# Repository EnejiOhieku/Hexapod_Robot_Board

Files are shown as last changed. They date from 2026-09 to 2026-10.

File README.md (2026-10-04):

# 18-DOF Hexapod Robot Controller Board (Rev 3.0)




[]()



A production-ready, high-power 4-layer robotics controller PCB designed for an **18-DOF Hexapod Robot**. Rev 3.0 is a major architectural upgrade introducing a **dedicated Vision Coprocessor** (second ESP32-S3-WROOM-1U-N8R8), a **BQ25886 2S LiPo fast charger** (replaces TP5100), **triple South-edge USB Type-C ports** (dedicated charging, main MCU, and vision MCU), an **OV3660/OV2640 DVP camera interface** with a 1–3W illumination LED driver, a **Sipeed MaixSense A010 3D ToF** sensor on a fully isolated 5V rail, a **dedicated Vision 3.3V ultra-low-noise LDO**, and an **external power switch connector**. The locomotion subsystem retains the proven dual 5A XL4015 buck split-rail architecture and dual PCA9685 uncrossed PWM routing.

---

## 3D Board Previews

<p align="center">
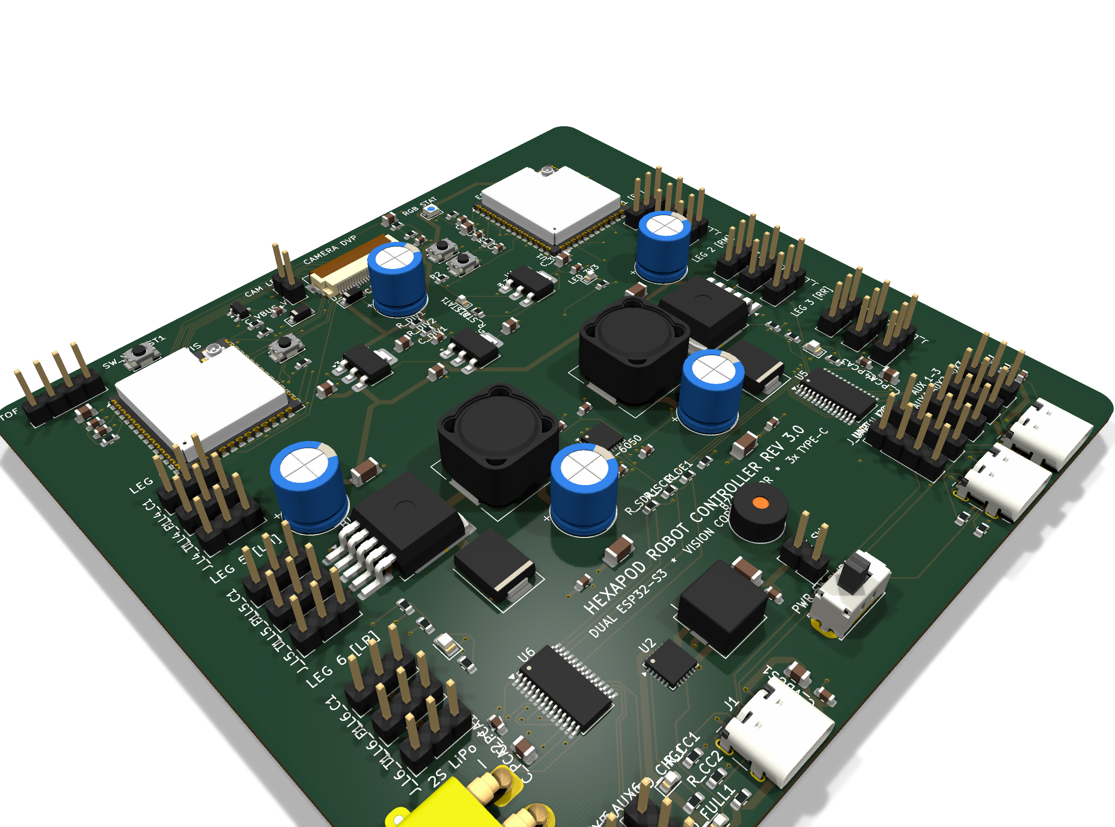
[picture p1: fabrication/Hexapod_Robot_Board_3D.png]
Hexapod Board 3D Perspective
  
</p>

<p align="center">
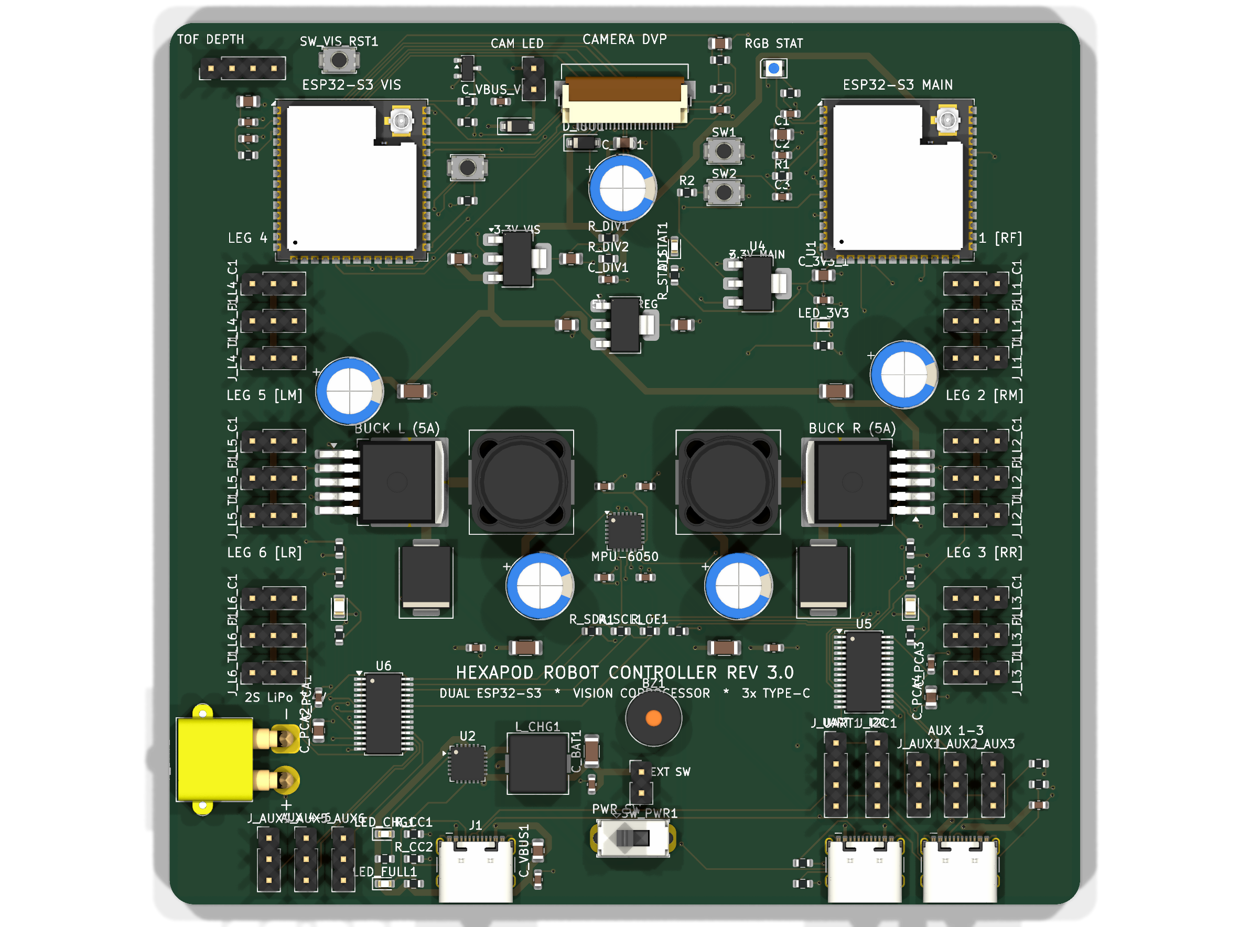
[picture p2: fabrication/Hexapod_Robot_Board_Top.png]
Top View
  
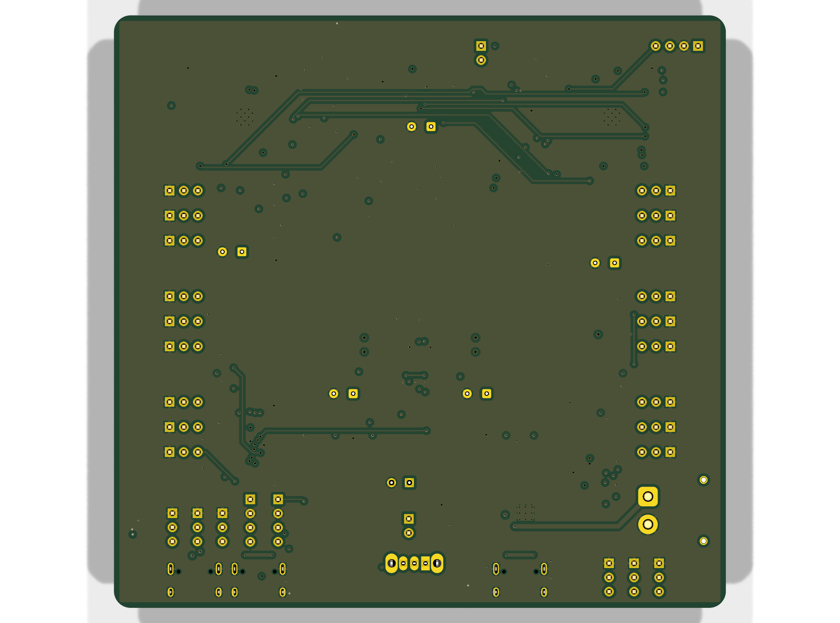
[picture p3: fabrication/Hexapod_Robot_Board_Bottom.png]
Bottom View
  
</p>

---

## System Architecture (Rev 3.0)

```mermaid
flowchart TD
    subgraph Power["Power & Battery Management"]
        J_CHG["USB Type-C (J_CHG) — Dedicated 2S Charger"] --> U2["BQ25886 2S LiPo Charger (8.4V / 1.5A)"]
        BAT["2S LiPo Battery (XT30PW, South Edge)"] --> SW["Main Power Switch (SW_PWR)"]
        U2 --> BAT
        SW --> VBAT_SW["Switched Battery Bus (VBAT_SW)"]
        VBAT_SW --> BUCK_L["Left Buck (XL4015, 5V / 5A) — U3_L"]
        VBAT_SW --> BUCK_R["Right Buck (XL4015, 5V / 5A) — U3_R"]
        VBAT_SW --> U4["Main 3.3V LDO (AP2112K / AMS1117-3.3) — U4"]
        VBAT_SW --> U_LDO_VIS["Vision 3.3V LDO (AMS1117-3.3) — U_LDO_VIS"]
        VBAT_SW --> U_REG_5V_TOF["Dedicated 5V ToF Regulator (AMS1117-5.0) — U_REG_5V_TOF"]
        VBAT_SW --> DIV["Battery Voltage Divider (R_DIV1 / R_DIV2)"]
    end

    subgraph Locomotion["Main Locomotion Controller (U1 — ESP32-S3-WROOM-1U)"]
        J_USB_MAIN["USB Type-C (J2) — Native USB / JTAG"] --> U1["ESP32-S3-WROOM-1U (Top-Right Edge, IPEX U.FL)"]
        U4 --> U1
        U1 -- "I2C (GPIO1/41)" --> U5["PCA9685 Left (0x40) — U5"]
        U1 -- "I2C (GPIO1/41)" --> U6["PCA9685 Right (0x41) — U6"]
        U1 -- "I2C (GPIO1/41)" --> U7["MPU-6050 6-Axis IMU (Centre, 0x68) — U7"]
        U7 -- "MPU_INT (GPIO10)" --> U1
        DIV -- "ADC (GPIO5)" --> U1
        U1 -- "GPIO48" --> LED_RGB_MAIN["WS2812B-2020 Status NeoPixel"]
    end

    subgraph Vision["Vision Coprocessor (U8 — ESP32-S3-WROOM-1U-N8R8)"]
        J_USB_VIS["USB Type-C (J3) — Vision USB / JTAG"] --> U8["ESP32-S3-WROOM-1U-N8R8 (Top-Left Edge, IPEX U.FL)"]
        U_LDO_VIS --> U8
        U8 -- "24-Pin 8-bit DVP (GPIO6-13, 15-18)" --> CAM["OV3660 / OV2640 Camera (J_CAM)"]
        U8 -- "SCCB I2C1 (GPIO4/5)" --> CAM
        U8 -- "UART1 (GPIO1/2)" --> TOF["Sipeed MaixSense A010 3D ToF (J_TOF)"]
        U8 -- "GPIO3 → R_CAM_LED → Q_CAM_LED" --> CAM_LED["1–3W Camera LED (J_CAM_LED)"]
        U_REG_5V_TOF -- "+5V_TOF (Isolated from Servos)" --> TOF
    end

    U1 <==>|"Inter-MCU Full-Duplex UART (GPIO43/44) + Frame Sync IRQ"| U8

    subgraph Servos["Servo Actuation (Split Left/Right Rails)"]
        BUCK_L --> V_SERVO_L["V_SERVO_L Plane (In2.Cu West)"]
        BUCK_R --> V_SERVO_R["V_SERVO_R Plane (In2.Cu East)"]
        U5 -- "PWM 0–11" --> SL["Left Legs 4, 5, 6 (9 Servos) + AUX 4–6"]
        U6 -- "PWM 0–11" --> SR["Right Legs 1, 2, 3 (9 Servos) + AUX 1–3"]
        V_SERVO_L --> SL
        V_SERVO_R --> SR
    end
```

---

## Key Hardware Features

### Dual-MCU Architecture
- **Main Locomotion MCU (`U1`)**: ESP32-S3-WROOM-1U — Dual-core Xtensa LX7 @ 240 MHz, 2.4 GHz Wi-Fi, BLE 5, 16 MB Flash. Placed on the **Top-Right edge** (`X=88.0, Y=2.5 mm`) with IPEX U.FL antenna facing North.
- **Vision Coprocessor (`U8`)**: ESP32-S3-WROOM-1U-N8R8 — Identical SoC, 8 MB PSRAM (Octal), pin-compatible with Zephyr's `esp32s3_eye` board definition. Placed on the **Top-Left edge** (`X=22.0, Y=2.5 mm`) with IPEX U.FL facing North.
- **Inter-MCU Link**: Full-duplex UART (`U1` GPIO43/44 ↔ `U8` GPIO43/44) at up to 3 Mbps, plus hardware Frame Sync / Alert IRQ (`U8` GPIO21 → `U1` GPIO4).

### Vision & Perception
- **Camera Interface**: 24-pin DVP FPC connector (`J_CAM`, top-centre `X=55.0, Y≈-11.0 mm`, rotated 180°) for OV3660 (3 MP) or OV2640 (2 MP). SCCB I²C via 4.7 kΩ pull-ups (`R_CAM_SCL`, `R_CAM_SDA`).
- **3D ToF Sensor**: Sipeed MaixSense A010 connector (`J_TOF`) at `(5.0, -11.0) mm`, powered by an isolated `+5V_TOF` linear rail with >60 dB PSRR to eliminate servo switching noise.
- **Camera Illumination**: 1–3 W white LED driver via AO3400A N-MOSFET (`Q_CAM_LED`), gate driven by Vision GPIO3 through 100 Ω series (`R_CAM_LED`) + 10 kΩ pull-down (`R_PD_CAM_LED`). External LED connector: `J_CAM_LED`.
- **Status NeoPixel**: WS2812B-2020 (`LED_RGB_MAIN`) driven by Main MCU GPIO48 via 330 Ω damping resistor (`R_NEO`).

### Power Architecture
| Rail | Source | Voltage | Max Current | Consumer |
|:---|:---|:---|:---|:---|
| `+VBAT` | 2S LiPo XT30PW | 6.0–8.4 V | 20 A peak | Raw battery |
| `VBAT_SW` | SW_PWR / J_SW_EXT | 6.0–8.4 V | 15 A | All regulators |
| `V_SERVO_L` | XL4015 Buck L (`U3_L`) | 5.0 V | 5 A cont. / 6 A pk | Left legs + AUX 4–6 |
| `V_SERVO_R` | XL4015 Buck R (`U3_R`) | 5.0 V | 5 A cont. / 6 A pk | Right legs + AUX 1–3 |
| `+3V3` | AP2112K LDO (`U4`) | 3.3 V | 600 mA | Main MCU, PCA9685s, IMU |
| `+3V3_VIS` | AMS1117-3.3 (`U_LDO_VIS`) | 3.3 V | 800 mA | Vision MCU, camera |
| `+5V_TOF` | AMS1117-5.0 (`U_REG_5V_TOF`) | 5.0 V | 800 mA | MaixSense A010 ToF (isolated) |
| `VBUS` | USB-C (`J_CHG`) | 5.0 V | 2.0 A | BQ25886 charger input |

- **Battery Management**: BQ25886 (VQFN-24) 2S LiPo fast charger — replaces TP5100. Supports USB BC1.2 detection, USB OTG boost, PowerPath management. Charge/standby LEDs: `LED_CHG`, `LED_FULL`.
- **External Power Switch**: 2-pin header `J_SW_EXT` allows robot chassis-mounted latching switch to gate `VBAT_SW`. Battery charges safely with electronics fully off.

### Triple South-Edge USB-C
All three USB-C receptacles co-located along the South board edge for a single chassis port bay cutout:
1. **`J_CHG` (`J1`, X≈37 mm)** — Dedicated 2S fast charger input. Zero data lines.
2. **`J_USB_MAIN` (`J2`, X≈95.5 mm)** — Main ESP32-S3 native USB / JTAG / gait telemetry.
3. **`J_USB_VISION` (`J3`, X≈84 mm)** — Vision ESP32-S3 native USB / JTAG / video stream.

### Inertial Measurement Unit
- **MPU-6050** (`U7`) at exact geometric centre of mass (`X=55.0, Y=45.0 mm`) with hardware interrupt to Main MCU GPIO10.

### Physical Specifications
- **Dimensions**: 110.0 × 90.0 mm, 3.0 mm corner radii.
- **Mounting**: 4× M3 holes (3.2 mm drill / 6.0 mm pad) at `(5,5)`, `(105,5)`, `(5,85)`, `(105,85)` mm.
- **Stackup**: 4-layer — `F.Cu` signals/PDN · `In1.Cu` solid GND · `In2.Cu` split `V_SERVO` planes · `B.Cu` GND flood/signals.

---

## Servo Channel Mapping

| Joint / Channel | Header | Controller | Ch | I²C Addr | Rail |
|:---|:---|:---|:---|:---|:---|
| **Right Front (RF) Coxa** | `J_L1_C` | PCA9685 Right (`U6`) | PWM 0 | `0x41` | `V_SERVO_R` |
| **Right Front (RF) Femur** | `J_L1_F` | PCA9685 Right (`U6`) | PWM 1 | `0x41` | `V_SERVO_R` |
| **Right Front (RF) Tibia** | `J_L1_T` | PCA9685 Right (`U6`) | PWM 2 | `0x41` | `V_SERVO_R` |
| **Right Middle (RM) Coxa** | `J_L2_C` | PCA9685 Right (`U6`) | PWM 3 | `0x41` | `V_SERVO_R` |
| **Right Middle (RM) Femur** | `J_L2_F` | PCA9685 Right (`U6`) | PWM 4 | `0x41` | `V_SERVO_R` |
| **Right Middle (RM) Tibia** | `J_L2_T` | PCA9685 Right (`U6`) | PWM 5 | `0x41` | `V_SERVO_R` |
| **Right Rear (RR) Coxa** | `J_L3_C` | PCA9685 Right (`U6`) | PWM 6 | `0x41` | `V_SERVO_R` |
| **Right Rear (RR) Femur** | `J_L3_F` | PCA9685 Right (`U6`) | PWM 7 | `0x41` | `V_SERVO_R` |
| **Right Rear (RR) Tibia** | `J_L3_T` | PCA9685 Right (`U6`) | PWM 8 | `0x41` | `V_SERVO_R` |
| **Left Front (LF) Coxa** | `J_L4_C` | PCA9685 Left (`U5`) | PWM 0 | `0x40` | `V_SERVO_L` |
| **Left Front (LF) Femur** | `J_L4_F` | PCA9685 Left (`U5`) | PWM 1 | `0x40` | `V_SERVO_L` |
| **Left Front (LF) Tibia** | `J_L4_T` | PCA9685 Left (`U5`) | PWM 2 | `0x40` | `V_SERVO_L` |
| **Left Middle (LM) Coxa** | `J_L5_C` | PCA9685 Left (`U5`) | PWM 3 | `0x40` | `V_SERVO_L` |
| **Left Middle (LM) Femur** | `J_L5_F` | PCA9685 Left (`U5`) | PWM 4 | `0x40` | `V_SERVO_L` |
| **Left Middle (LM) Tibia** | `J_L5_T` | PCA9685 Left (`U5`) | PWM 5 | `0x40` | `V_SERVO_L` |
| **Left Rear (LR) Coxa** | `J_L6_C` | PCA9685 Left (`U5`) | PWM 6 | `0x40` | `V_SERVO_L` |
| **Left Rear (LR) Femur** | `J_L6_F` | PCA9685 Left (`U5`) | PWM 7 | `0x40` | `V_SERVO_L` |
| **Left Rear (LR) Tibia** | `J_L6_T` | PCA9685 Left (`U5`) | PWM 8 | `0x40` | `V_SERVO_L` |
| **Auxiliary PWM 1–3** | `J_AUX1–3` | PCA9685 Right (`U6`) | PWM 9–11 | `0x41` | `V_SERVO_R` |
| **Auxiliary PWM 4–6** | `J_AUX4–6` | PCA9685 Left (`U5`) | PWM 9–11 | `0x40` | `V_SERVO_L` |

---

## GPIO Assignments

### Main Locomotion MCU (`U1` — ESP32-S3-WROOM-1U)
| GPIO | Function | Direction | Connected To |
|:---|:---|:---|:---|
| GPIO1 | I2C SCL | Output | PCA9685 L/R, MPU-6050 |
| GPIO41 | I2C SDA | Bidirectional | PCA9685 L/R, MPU-6050 |
| GPIO4 | Frame Sync IRQ | Input | Vision MCU GPIO21 |
| GPIO5 | Battery ADC | Input | `R_DIV1`/`R_DIV2` voltage divider |
| GPIO6 | CHG_STAT | Input | BQ25886 `STAT` pin |
| GPIO7 | CHG_PG | Input | BQ25886 `PG` pin (Power Good) |
| GPIO10 | MPU_INT | Input | MPU-6050 INT |
| GPIO19/20 | USB D-/D+ | Bidirectional | `J_USB_MAIN` (J2) |
| GPIO43 | Inter-MCU TX | Output | Vision MCU GPIO44 |
| GPIO44 | Inter-MCU RX | Input | Vision MCU GPIO43 |
| GPIO48 | NeoPixel Data | Output | `R_NEO` → `LED_RGB_MAIN` |

### Vision Coprocessor (`U8` — ESP32-S3-WROOM-1U-N8R8)
| GPIO | Function | Direction | Connected To |
|:---|:---|:---|:---|
| GPIO1 | ToF UART RX | Input | A010 TX (UART1) |
| GPIO2 | ToF UART TX | Output | A010 RX (UART1) |
| GPIO3 | Camera LED PWM | Output | `R_CAM_LED` → `Q_CAM_LED` gate |
| GPIO4 | SCCB SDA (I2C1) | Bidirectional | Camera SIOD, 4.7 kΩ pull-up |
| GPIO5 | SCCB SCL (I2C1) | Output | Camera SIOC, 4.7 kΩ pull-up |
| GPIO6 | DVP VSYNC | Input | Camera VSYNC |
| GPIO7 | DVP HREF | Input | Camera HREF |
| GPIO8–13 | DVP D2–D7 | Input | Camera Y4–Y9 |
| GPIO15 | DVP XCLK | Output | Camera XCLK (10–24 MHz) |
| GPIO16–18 | DVP D0–D2 | Input | Camera Y2–Y4 |
| GPIO19/20 | USB D-/D+ | Bidirectional | `J_USB_VISION` (J3) |
| GPIO21 | Frame Sync IRQ | Output | Main MCU GPIO4 |
| GPIO38 | Camera PWDN | Output | Camera PWDN, 10 kΩ pull-down |
| GPIO43 | Inter-MCU TX | Output | Main MCU GPIO44 |
| GPIO44 | Inter-MCU RX | Input | Main MCU GPIO43 |

---

## Project Structure

```
Hexapod_Robot_Board/
├── Hexapod_Robot_Board.kicad_pro       # Master KiCad 10.0.6 project file
├── Hexapod_Robot_Board.kicad_sch       # Rev 3.0 schematic (dual-MCU, triple USB-C)
├── Hexapod_Robot_Board.kicad_pcb       # 4-layer routed PCB layout
├── Hexapod_Robot_Board.net             # Complete netlist (98 nets)
├── README.md                           # This document
├── 3dmodels/                           # Custom 3D STEP component packages
│   ├── ESP32-S3-WROOM-1U.step
│   ├── MPU-6050.step
│   ├── LED_WS2812B-2020.step
│   └── Hirose_FH12-24S-0.5SH_1x24-1MP_P0.50mm_Horizontal.step
├── fabrication/                        # Manufacturing deliverable package
│   ├── Hexapod_Robot_Board-gerbers.zip
│   ├── Hexapod_Robot_Board-cpl-jlcpcb.csv
│   ├── Hexapod_Robot_Board-bom-jlcpcb.csv
│   ├── Hexapod_Robot_Board.step
│   ├── Hexapod_Robot_Board_Schematic.pdf
│   └── *.png                           # 2D + 3D renders
├── reports/                            # Verification reports
│   ├── Hexapod_Robot_Board-drc.rpt
│   ├── Hexapod_Robot_Board-erc.rpt
│   └── Hexapod_Robot_Board-stats.txt
└── scripts/                            # Python automation suite
    ├── export_fabrication.py           # One-click manufacturing pipeline
    ├── run_final_perfect_route.py      # Freerouting solver
    └── README.md
```

---

## Verification & Compliance

- **ERC**: Passed — **0 errors, 0 warnings** ([`reports/Hexapod_Robot_Board-erc.rpt`](reports/Hexapod_Robot_Board-erc.rpt)).
- **DRC**: Passed — **0 violations, 0 unconnected items** ([`reports/Hexapod_Robot_Board-drc.rpt`](reports/Hexapod_Robot_Board-drc.rpt)).
- **Manufacturability**: JLCPCB / PCBWay 4-layer standard constraints (0.15 mm clearance, 0.20 mm min track, 0.30 mm min drill, 45° mitered geometry).

---

## Revision History

| Rev | Date | Summary |
|:---|:---|:---|
| **3.0** | 2026-10-04 | Vision Coprocessor (ESP32-S3-WROOM-1U-N8R8), BQ25886 2S charger, triple South USB-C, DVP camera, MaixSense A010 ToF on isolated +5V rail, dedicated Vision 3.3V LDO, camera LED driver, inter-MCU UART link, external power switch header, WS2812B NeoPixel. Schematic/PCB annotated and synced. |
| **2.0** | 2026-10-01 | ESP32-S3-WROOM-1U, dual XL4015 5A buck split rails, MPU-6050 at CoM, South-edge USB-C charging via TP5100, dual PCA9685 uncrossed PWM, 4-layer routing, 0 DRC/ERC. |
| **1.0** | 2026-09-28 | Initial 18-DOF hexapod controller. ESP32-S3, single buck, TP5100 charger, dual PCA9685. |

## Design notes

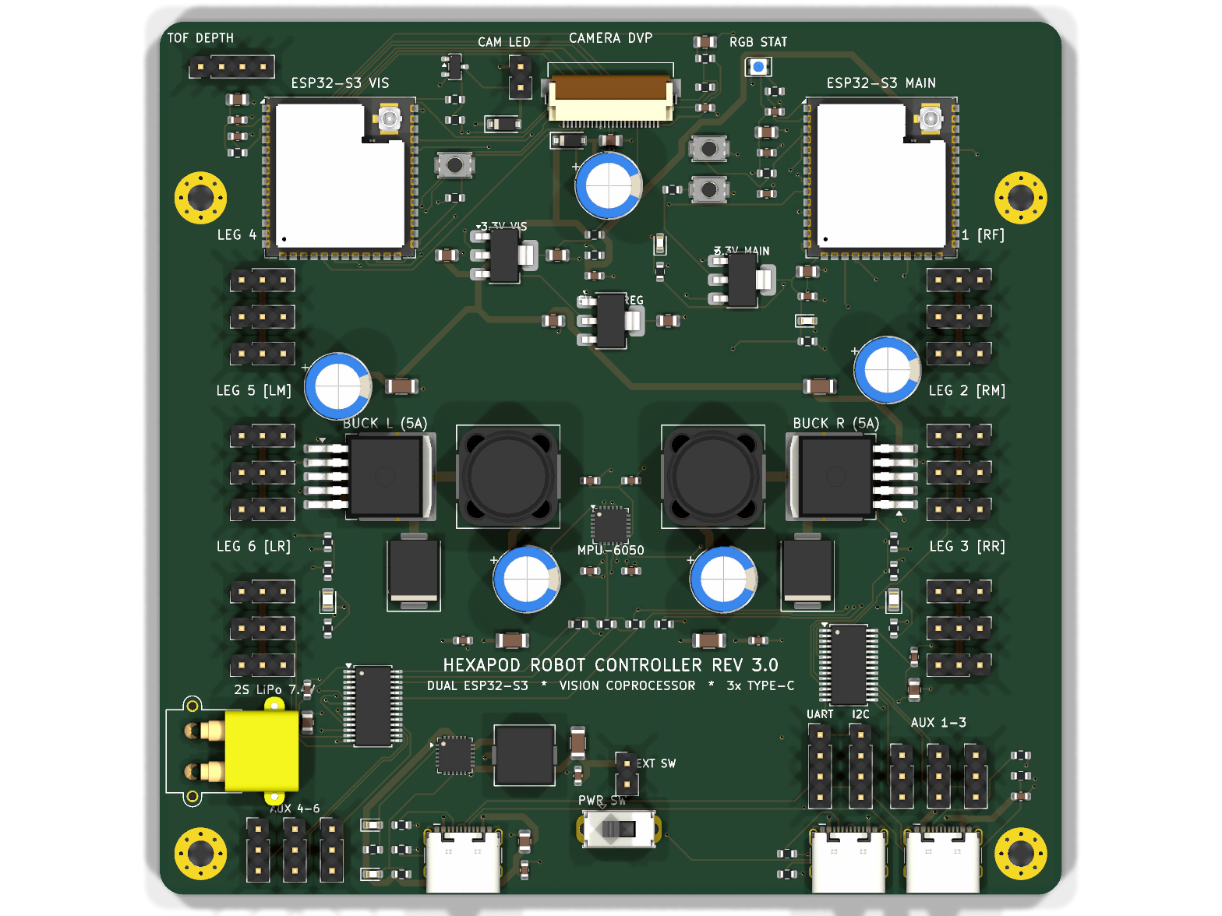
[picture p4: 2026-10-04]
reports/current_board.png

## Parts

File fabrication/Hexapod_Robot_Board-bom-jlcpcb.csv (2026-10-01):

Item | Designator | Quantity | Value | Package/Footprint | Type | LCSC Part #
1 | C2, C_3V3_2, C_BAT2, C_DIV, C_MPU1, C_MPU2, C_MPU3, C_OUT3_L, C_OUT3_R, C_PCA1, C_PCA3, C_VBUS2 | 12 | 100nF | C_0603_1608Metric | SMD | C14663
2 | C3 | 1 | 1uF | C_0603_1608Metric | SMD | C15849
3 | C_MPU5 | 1 | 2.2nF | C_0603_1608Metric | SMD | C1604
4 | C1, C_ISO2, C_PCA2, C_PCA4, C_VBUS1 | 5 | 10uF | C_0805_2012Metric | SMD | C15850
5 | C_3V3_1 | 1 | 22uF | C_0805_2012Metric | SMD | C45783
6 | C_BAT1 | 1 | 22uF | C_1206_3216Metric | SMD | C45783
7 | C_OUT2_L, C_OUT2_R | 2 | 22uF_16V | C_1206_3216Metric | SMD
8 | C_IN2_L, C_IN2_R | 2 | 22uF_25V | C_1206_3216Metric | SMD
9 | D_CATCH_L, D_CATCH_R | 2 | SS54 | D_SMC | SMD | C22452
10 | D_ISO | 1 | SS14 | D_SOD-123 | SMD | C2410
11 | U1 | 1 | ESP32-S3-WROOM-1U | ESP32-S3-WROOM-1U | SMD | C2934560
12 | U7 | 1 | MPU-6050 | InvenSense_QFN-24_4x4mm_P0.5mm | SMD | C24112
13 | LED_3V3 | 1 | Blue | LED_0603_1608Metric | SMD
14 | D_STAT, LED_FULL | 2 | Green | LED_0603_1608Metric | SMD
15 | LED_CHG | 1 | Red | LED_0603_1608Metric | SMD
16 | LED_L, LED_R | 2 | Green | LED_0805_2012Metric | SMD
17 | L_SERVO_L, L_SERVO_R | 2 | 10uH_10A | L_12x12mm_H8mm | SMD
18 | L_CHG | 1 | 2.2uH_4A | L_7.3x7.3_H4.5 | SMD
19 | U2 | 1 | BQ25886 | QFN-24-1EP_4x4mm_P0.5mm_EP2.7x2.7mm_ThermalVias | SMD
20 | R_DIV1 | 1 | 100k_1% | R_0603_1608Metric | SMD
21 | R1, R2, R_OE | 3 | 10k | R_0603_1608Metric | SMD | C25804
22 | R_FB1_L, R_FB1_R | 2 | 10k_1% | R_0603_1608Metric | SMD
23 | R_3V3_LED, R_BZ, R_CHG, R_FULL, R_LED_L, R_LED_R, R_STAT | 7 | 1k | R_0603_1608Metric | SMD | C21190
24 | R_FB2_L, R_FB2_R | 2 | 3.16k_1% | R_0603_1608Metric | SMD
25 | R_DIV2 | 1 | 33k_1% | R_0603_1608Metric | SMD
26 | R_SCL, R_SDA | 2 | 4.7k | R_0603_1608Metric | SMD
27 | R_CC1, R_CC2 | 2 | 5.1k | R_0603_1608Metric | SMD | C23186
28 | U4 | 1 | AMS1117-3.3 | SOT-223-3_TabPin2 | SMD | C6186
29 | SW2 | 1 | BOOT | SW_Push_SPST_NO_Alps_SKRK | SMD
30 | SW1 | 1 | RESET | SW_Push_SPST_NO_Alps_SKRK | SMD
31 | U3_L, U3_R | 2 | XL4015 | TO-263-5_TabPin3 | SMD | C73335
32 | U5 | 1 | PCA9685_1 | TSSOP-28_4.4x9.7mm_P0.65mm | SMD
33 | U6 | 1 | PCA9685_2 | TSSOP-28_4.4x9.7mm_P0.65mm | SMD
34 | J1 | 1 | USB-C | USB_C_Receptacle_HCTL_HC-TYPE-C-16P-01A | SMD
35 | J_BAT | 1 | 2S_LiPo | AMASS_XT30PW-M_1x02_P2.50mm_Horizontal | THT
36 | C_OUT1_L, C_OUT1_R | 2 | 1000uF_10V | CP_Radial_D8.0mm_P3.50mm | THT
37 | C_IN1_L, C_IN1_R | 2 | 100uF_25V | CP_Radial_D8.0mm_P3.50mm | THT
38 | C_ISO1 | 1 | 220uF_16V | CP_Radial_D8.0mm_P3.50mm | THT
39 | H1, H2, H3, H4 | 4 | M3 | MountingHole_3.2mm_M3_Pad_Via | THT
40 | J_AUX1 | 1 | AUX_1 | PinHeader_1x03_P2.54mm_Vertical | THT
41 | J_AUX2 | 1 | AUX_2 | PinHeader_1x03_P2.54mm_Vertical | THT
42 | J_AUX3 | 1 | AUX_3 | PinHeader_1x03_P2.54mm_Vertical | THT
43 | J_AUX4 | 1 | AUX_4 | PinHeader_1x03_P2.54mm_Vertical | THT
44 | J_AUX5 | 1 | AUX_5 | PinHeader_1x03_P2.54mm_Vertical | THT
45 | J_AUX6 | 1 | AUX_6 | PinHeader_1x03_P2.54mm_Vertical | THT
46 | J_L4_C | 1 | LF_Coxa | PinHeader_1x03_P2.54mm_Vertical | THT
47 | J_L4_F | 1 | LF_Femur | PinHeader_1x03_P2.54mm_Vertical | THT
48 | J_L4_T | 1 | LF_Tibia | PinHeader_1x03_P2.54mm_Vertical | THT
49 | J_L5_C | 1 | LM_Coxa | PinHeader_1x03_P2.54mm_Vertical | THT
50 | J_L5_F | 1 | LM_Femur | PinHeader_1x03_P2.54mm_Vertical | THT
51 | J_L5_T | 1 | LM_Tibia | PinHeader_1x03_P2.54mm_Vertical | THT
52 | J_L6_C | 1 | LR_Coxa | PinHeader_1x03_P2.54mm_Vertical | THT
53 | J_L6_F | 1 | LR_Femur | PinHeader_1x03_P2.54mm_Vertical | THT
54 | J_L6_T | 1 | LR_Tibia | PinHeader_1x03_P2.54mm_Vertical | THT
55 | J_L1_C | 1 | RF_Coxa | PinHeader_1x03_P2.54mm_Vertical | THT
56 | J_L1_F | 1 | RF_Femur | PinHeader_1x03_P2.54mm_Vertical | THT
57 | J_L1_T | 1 | RF_Tibia | PinHeader_1x03_P2.54mm_Vertical | THT
58 | J_L2_C | 1 | RM_Coxa | PinHeader_1x03_P2.54mm_Vertical | THT
59 | J_L2_F | 1 | RM_Femur | PinHeader_1x03_P2.54mm_Vertical | THT
60 | J_L2_T | 1 | RM_Tibia | PinHeader_1x03_P2.54mm_Vertical | THT
61 | J_L3_C | 1 | RR_Coxa | PinHeader_1x03_P2.54mm_Vertical | THT
62 | J_L3_F | 1 | RR_Femur | PinHeader_1x03_P2.54mm_Vertical | THT
63 | J_L3_T | 1 | RR_Tibia | PinHeader_1x03_P2.54mm_Vertical | THT
64 | J_I2C | 1 | I2C_BUS | PinHeader_1x04_P2.54mm_Vertical | THT
65 | J_UART | 1 | UART_DEBUG | PinHeader_1x04_P2.54mm_Vertical | THT
66 | SW_PWR | 1 | POWER | SW_Slide_SPDT_Straight_CK_OS102011MS2Q | THT

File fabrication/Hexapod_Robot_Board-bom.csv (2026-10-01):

Designator | Value | Footprint | Quantity
C1,C_ISO2,C_PCA2,C_PCA4,C_VBUS1 | 10uF | Capacitor_SMD:C_0805_2012Metric | 5
C2,C_3V3_2,C_BAT2,C_DIV?,C_MPU1-C_MPU3,C_OUT3_L?,C_OUT3_R?,C_PCA1,C_PCA3,C_VBUS2 | 100nF | Capacitor_SMD:C_0603_1608Metric | 12
C3 | 1uF | Capacitor_SMD:C_0603_1608Metric | 1
C_3V3_1 | 22uF | Capacitor_SMD:C_0805_2012Metric | 1
C_BAT1,C_IN2_L?,C_IN2_R? | 22uF_25V | Capacitor_SMD:C_1206_3216Metric | 3
C_IN1_L?,C_IN1_R? | 100uF_25V | Capacitor_THT:CP_Radial_D8.0mm_P3.50mm | 2
C_ISO1 | 220uF_16V | Capacitor_THT:CP_Radial_D8.0mm_P3.50mm | 1
C_MPU5 | 2.2nF | Capacitor_SMD:C_0603_1608Metric | 1
C_OUT1_L?,C_OUT1_R? | 1000uF_10V | Capacitor_THT:CP_Radial_D8.0mm_P3.50mm | 2
C_OUT2_L?,C_OUT2_R? | 22uF_16V | Capacitor_SMD:C_1206_3216Metric | 2
D_CATCH_L?,D_CATCH_R? | SS54 | Diode_SMD:D_SMC | 2
D_ISO? | SS14 | Diode_SMD:D_SOD-123 | 1
D_STAT?,LED_FULL? | Green | LED_SMD:LED_0603_1608Metric | 2
J1 | USB-C | Connector_USB:USB_C_Receptacle_HCTL_HC-TYPE-C-16P-01A | 1
J_AUX1 | AUX_PWM_18 | Connector_PinHeader_2.54mm:PinHeader_1x03_P2.54mm_Vertical | 1
J_AUX2 | AUX_PWM_19 | Connector_PinHeader_2.54mm:PinHeader_1x03_P2.54mm_Vertical | 1
J_AUX3 | AUX_PWM_20 | Connector_PinHeader_2.54mm:PinHeader_1x03_P2.54mm_Vertical | 1
J_AUX4 | AUX_PWM_21 | Connector_PinHeader_2.54mm:PinHeader_1x03_P2.54mm_Vertical | 1
J_AUX5 | AUX_PWM_22 | Connector_PinHeader_2.54mm:PinHeader_1x03_P2.54mm_Vertical | 1
J_AUX6 | AUX_PWM_23 | Connector_PinHeader_2.54mm:PinHeader_1x03_P2.54mm_Vertical | 1
J_BAT? | 2S_LiPo_7.4V | Connector_AMASS:AMASS_XT30PW-M_1x02_P2.50mm_Horizontal | 1
J_I2C? | I2C_BUS | Connector_PinHeader_2.54mm:PinHeader_1x04_P2.54mm_Vertical | 1
J_L1_C? | L1_Coxa | Connector_PinHeader_2.54mm:PinHeader_1x03_P2.54mm_Vertical | 1
J_L1_F? | L1_Femur | Connector_PinHeader_2.54mm:PinHeader_1x03_P2.54mm_Vertical | 1
J_L1_T? | L1_Tibia | Connector_PinHeader_2.54mm:PinHeader_1x03_P2.54mm_Vertical | 1
J_L2_C? | L2_Coxa | Connector_PinHeader_2.54mm:PinHeader_1x03_P2.54mm_Vertical | 1
J_L2_F? | L2_Femur | Connector_PinHeader_2.54mm:PinHeader_1x03_P2.54mm_Vertical | 1
J_L2_T? | L2_Tibia | Connector_PinHeader_2.54mm:PinHeader_1x03_P2.54mm_Vertical | 1
J_L3_C? | L3_Coxa | Connector_PinHeader_2.54mm:PinHeader_1x03_P2.54mm_Vertical | 1
J_L3_F? | L3_Femur | Connector_PinHeader_2.54mm:PinHeader_1x03_P2.54mm_Vertical | 1
J_L3_T? | L3_Tibia | Connector_PinHeader_2.54mm:PinHeader_1x03_P2.54mm_Vertical | 1
J_L4_C? | L4_Coxa | Connector_PinHeader_2.54mm:PinHeader_1x03_P2.54mm_Vertical | 1
J_L4_F? | L4_Femur | Connector_PinHeader_2.54mm:PinHeader_1x03_P2.54mm_Vertical | 1
J_L4_T? | L4_Tibia | Connector_PinHeader_2.54mm:PinHeader_1x03_P2.54mm_Vertical | 1
J_L5_C? | L5_Coxa | Connector_PinHeader_2.54mm:PinHeader_1x03_P2.54mm_Vertical | 1
J_L5_F? | L5_Femur | Connector_PinHeader_2.54mm:PinHeader_1x03_P2.54mm_Vertical | 1
J_L5_T? | L5_Tibia | Connector_PinHeader_2.54mm:PinHeader_1x03_P2.54mm_Vertical | 1
J_L6_C? | L6_Coxa | Connector_PinHeader_2.54mm:PinHeader_1x03_P2.54mm_Vertical | 1
J_L6_F? | L6_Femur | Connector_PinHeader_2.54mm:PinHeader_1x03_P2.54mm_Vertical | 1
J_L6_T? | L6_Tibia | Connector_PinHeader_2.54mm:PinHeader_1x03_P2.54mm_Vertical | 1
J_UART? | UART_DEBUG | Connector_PinHeader_2.54mm:PinHeader_1x04_P2.54mm_Vertical | 1
LED_3V3 | Blue | LED_SMD:LED_0603_1608Metric | 1
LED_CHG? | Red | LED_SMD:LED_0603_1608Metric | 1
LED_L?,LED_R? | Green | LED_SMD:LED_0805_2012Metric | 2
L_CHG? | 2.2uH_4A | Inductor_SMD:L_7.3x7.3_H4.5 | 1
L_SERVO_L?,L_SERVO_R? | 10uH_10A | Inductor_SMD:L_12x12mm_H8mm | 2
R1,R2,R_OE? | 10k | Resistor_SMD:R_0603_1608Metric | 3
R_3V3_LED?,R_BZ?,R_CHG?,R_FULL?,R_LED_L?,R_LED_R?,R_STAT? | 1k | Resistor_SMD:R_0603_1608Metric | 7
R_CC1,R_CC2 | 5.1k_1% | Resistor_SMD:R_0603_1608Metric | 2
R_DIV1 | 100k_1% | Resistor_SMD:R_0603_1608Metric | 1
R_DIV2 | 33k_1% | Resistor_SMD:R_0603_1608Metric | 1
R_FB1_L?,R_FB1_R? | 10k_1% | Resistor_SMD:R_0603_1608Metric | 2
R_FB2_L?,R_FB2_R? | 3.16k_1% | Resistor_SMD:R_0603_1608Metric | 2
R_SCL?,R_SDA? | 4.7k | Resistor_SMD:R_0603_1608Metric | 2
SW1 | RESET | Button_Switch_SMD:SW_Push_SPST_NO_Alps_SKRK | 1
SW2 | BOOT | Button_Switch_SMD:SW_Push_SPST_NO_Alps_SKRK | 1
SW_PWR? | POWER_SWITCH | Button_Switch_THT:SW_Slide_SPDT_Straight_CK_OS102011MS2Q | 1
U1 | ESP32-S3-WROOM-1U | RF_Module:ESP32-S3-WROOM-1U | 1
U2 | BQ25886 | Package_DFN_QFN:QFN-24-1EP_4x4mm_P0.5mm_EP2.7x2.7mm_ThermalVias | 1
U3_L?,U3_R? | XL4015 | Package_TO_SOT_SMD:TO-263-5_TabPin3 | 2
U4 | AMS1117-3.3 | Package_TO_SOT_SMD:SOT-223-3_TabPin2 | 1
U5 | PCA9685_0x40 | Package_SO:TSSOP-28_4.4x9.7mm_P0.65mm | 1
U6 | PCA9685_0x41 | Package_SO:TSSOP-28_4.4x9.7mm_P0.65mm | 1
U7 | MPU-6050 | Sensor_Motion:InvenSense_QFN-24_4x4mm_P0.5mm | 1

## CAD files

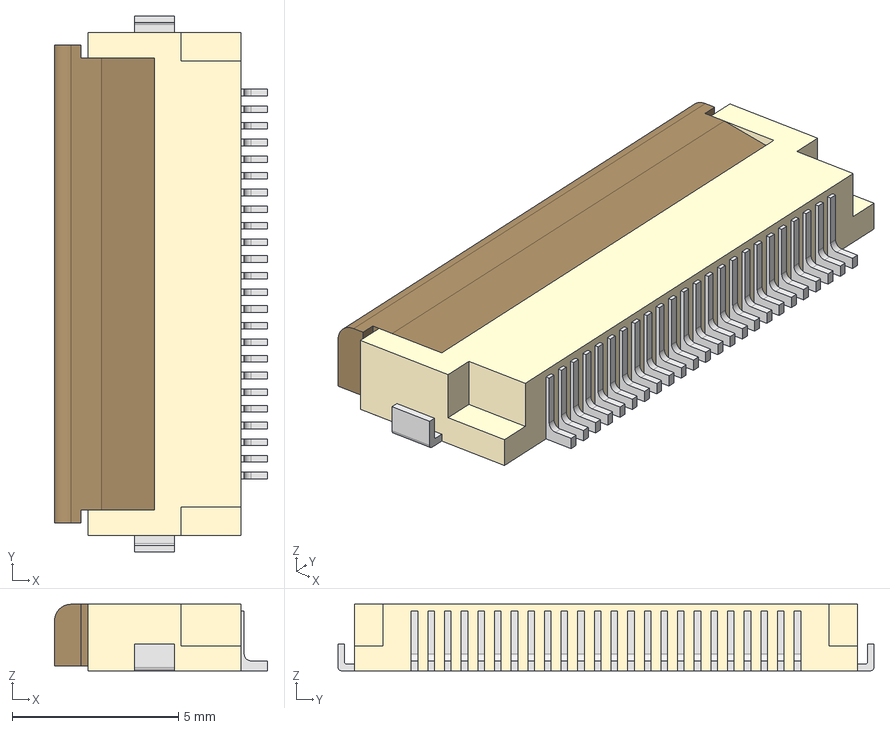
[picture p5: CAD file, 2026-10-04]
3dmodels/Hirose_FH12-24S-0.5SH_1x24-1MP_P0.50mm_Horizontal.step
6.40 x 16.1 x 2.00 mm

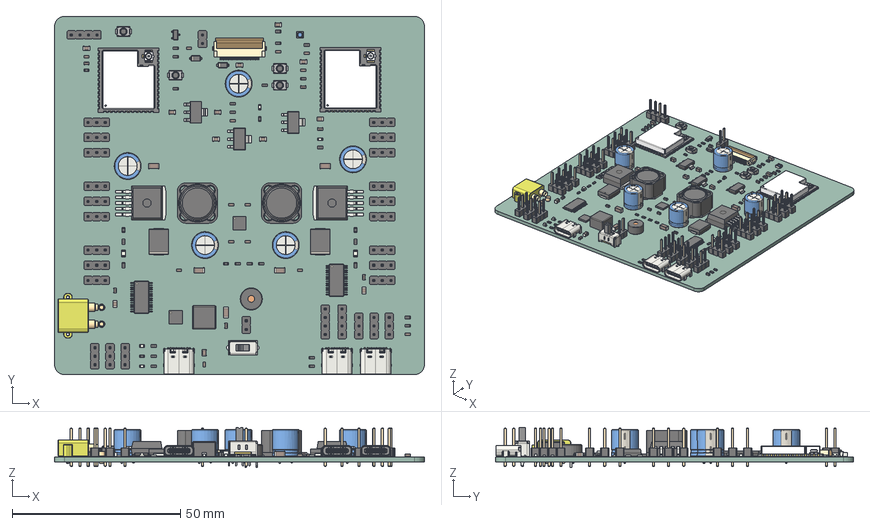
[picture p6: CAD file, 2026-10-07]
fabrication/Hexapod_Robot_Board.step
110.0 x 106.5 x 12.0 mm
PinHeader_1x03_P254mm_Vertical x 24
R_0603_1608Metric x 31
C_0603_1608Metric x 20
D_SMC x 2
C_1206_3216Metric x 5
CQ assembly x 2
a648ce36-9c39-11ed-93f0-dde97e994e83 x 2
a648ce37-9c39-11ed-93f0-dde97e994e83 x 2
a648ce37-9c39-11ed-93f0-dde97e994e83_part x 2
a648ce38-9c39-11ed-93f0-dde97e994e83 x 2
a648ce38-9c39-11ed-93f0-dde97e994e83_part x 2
a648ce39-9c39-11ed-93f0-dde97e994e83 x 2
a648ce39-9c39-11ed-93f0-dde97e994e83_part x 2
L_Coilcraft_MSS1278-XXX x 2
C_0805_2012Metric x 12
XT30PW-M
SW_Push_SPST_NO_Alps_SKRK x 4
LED_0805_2012Metric x 2
PinHeader_1x04_P254mm_Vertical x 3
SOT-223 x 3
D_SOD-123 x 2
TSSOP-28_4.4x9.7mm_P0.65mm x 2
CP_Radial_D80mm_P350mm x 5
PinHeader_1x02_P254mm_Vertical x 2
LED_0603_1608Metric x 4
R0201_20210301.STEP^R0201_20210301.STEP_Submodel-R0201_part_ DesignRootModel_ESP32-S3-WROOM-1U(2)_ESP32-S3-WROOM-1U_2 x 16
L0201_20210301.STEP^L0201_20210301.STEP_Submodel-L0201_part_ DesignRootModel_ESP32-S3-WROOM-1U(2)_ESP32-S3-WROOM-1U_2 x 4
C0201_20210301.STEP^C0201_20210301.STEP_Submodel-C0201_part_ DesignRootModel_ESP32-S3-WROOM-1U(2)_ESP32-S3-WROOM-1U_2 x 26
C0402_20210301.STEP^C0402_20210301.STEP_Submodel-C0402_part_ DesignRootModel_ESP32-S3-WROOM-1U(2)_ESP32-S3-WROOM-1U_2 x 2
I-IPEX.STEP^I-IPEX.STEP_Submodel-IPEX_3P_part_DesignRootModel_ ESP32-S3-WROOM-1U(2)_ESP32-S3-WROOM-1U_2 x 2
DFN1006.STEP^DFN1006.STEP_Submodel-SOD882_part_DesignRootModel_ ESP32-S3-WROOM-1U(2)_ESP32-S3-WROOM-1U_2 x 2
SOP8_rev1_20210308.STEP^SOP8_rev1_20210308.STEP_Submodel-SOP8_1P27_6P6_ part_DesignRootModel_ESP32-S3-WROOM-1U(2)_ESP32-S3-WROOM-1U_2 x 2
ESP32-S3_20210301.STEP^ESP32-S3_20210301.STEP_Submodel-QFN56_0P4_7_ part_DesignRootModel_ESP32-S3-WROOM-1U(2)_ESP32-S3-WROOM-1U_2 x 2
XTAL3225_20210301.STEP^XTAL3225_20210301.STEP_Submodel-XTAL3225_part_ DesignRootModel_ESP32-S3-WROOM-1U(2)_ESP32-S3-WROOM-1U_2 x 2
uid__4-111^DesignRootModel_ESP32-S3-WROOM-1U(2)_ESP32-S3-WROOM-1U_2 x 2
uid__4-112^DesignRootModel_ESP32-S3-WROOM-1U(2)_ESP32-S3-WROOM-1U_2 x 2
uid__4-113^DesignRootModel_ESP32-S3-WROOM-1U(2)_ESP32-S3-WROOM-1U_2 x 2
uid__4-130^DesignRootModel_ESP32-S3-WROOM-1U(2)_ESP32-S3-WROOM-1U_2 x 2
uid__4-131^DesignRootModel_ESP32-S3-WROOM-1U(2)_ESP32-S3-WROOM-1U_2 x 2
uid__4-132^DesignRootModel_ESP32-S3-WROOM-1U(2)_ESP32-S3-WROOM-1U_2 x 2
uid__4-148^DesignRootModel_ESP32-S3-WROOM-1U(2)_ESP32-S3-WROOM-1U_2 x 2
uid__4-149^DesignRootModel_ESP32-S3-WROOM-1U(2)_ESP32-S3-WROOM-1U_2 x 2
uid__4-150^DesignRootModel_ESP32-S3-WROOM-1U(2)_ESP32-S3-WROOM-1U_2 x 2
uid__1-253^DesignRootModel_ESP32-S3-WROOM-1U(2)_ESP32-S3-WROOM-1U_2 x 2
uid__1-254^DesignRootModel_ESP32-S3-WROOM-1U(2)_ESP32-S3-WROOM-1U_2 x 2
uid__1-256^DesignRootModel_ESP32-S3-WROOM-1U(2)_ESP32-S3-WROOM-1U_2 x 2
uid__1-257^DesignRootModel_ESP32-S3-WROOM-1U(2)_ESP32-S3-WROOM-1U_2 x 2
uid__1-266^DesignRootModel_ESP32-S3-WROOM-1U(2)_ESP32-S3-WROOM-1U_2 x 2
uid__1-269^DesignRootModel_ESP32-S3-WROOM-1U(2)_ESP32-S3-WROOM-1U_2 x 2
uid__1-270^DesignRootModel_ESP32-S3-WROOM-1U(2)_ESP32-S3-WROOM-1U_2 x 2
uid__1-271^DesignRootModel_ESP32-S3-WROOM-1U(2)_ESP32-S3-WROOM-1U_2 x 2
uid__1-272^DesignRootModel_ESP32-S3-WROOM-1U(2)_ESP32-S3-WROOM-1U_2 x 2
uid__1-273^DesignRootModel_ESP32-S3-WROOM-1U(2)_ESP32-S3-WROOM-1U_2 x 2
uid__1-274^DesignRootModel_ESP32-S3-WROOM-1U(2)_ESP32-S3-WROOM-1U_2 x 2
uid__1-275^DesignRootModel_ESP32-S3-WROOM-1U(2)_ESP32-S3-WROOM-1U_2 x 2
uid__1-276^DesignRootModel_ESP32-S3-WROOM-1U(2)_ESP32-S3-WROOM-1U_2 x 2
uid__1-277^DesignRootModel_ESP32-S3-WROOM-1U(2)_ESP32-S3-WROOM-1U_2 x 2
uid__1-280^DesignRootModel_ESP32-S3-WROOM-1U(2)_ESP32-S3-WROOM-1U_2 x 2
uid__1-292^DesignRootModel_ESP32-S3-WROOM-1U(2)_ESP32-S3-WROOM-1U_2 x 2
uid__1-293^DesignRootModel_ESP32-S3-WROOM-1U(2)_ESP32-S3-WROOM-1U_2 x 2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

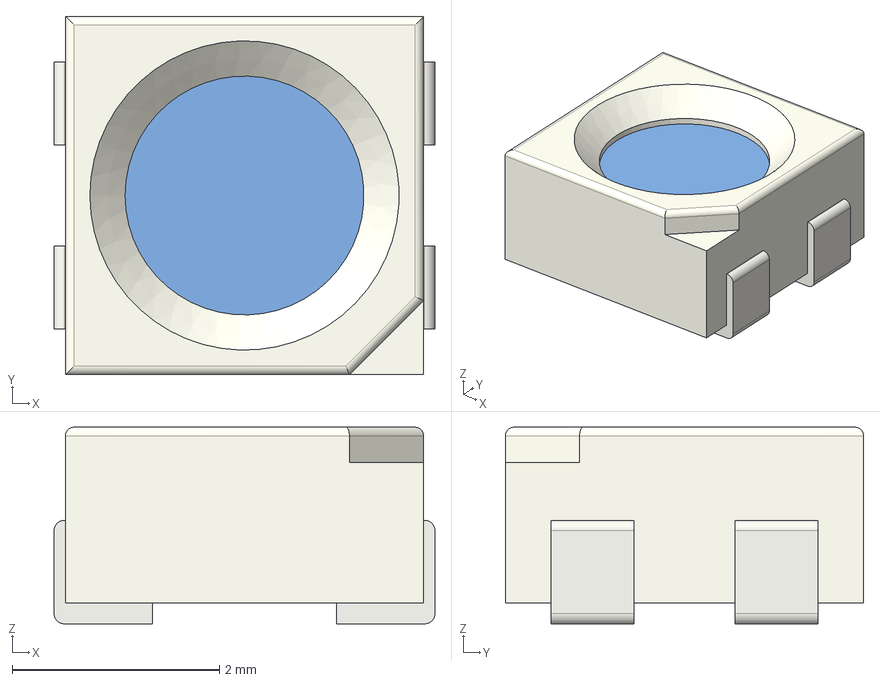
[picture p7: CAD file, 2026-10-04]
3dmodels/LED_WS2812B-2020.step
3.68 x 3.46 x 1.90 mm

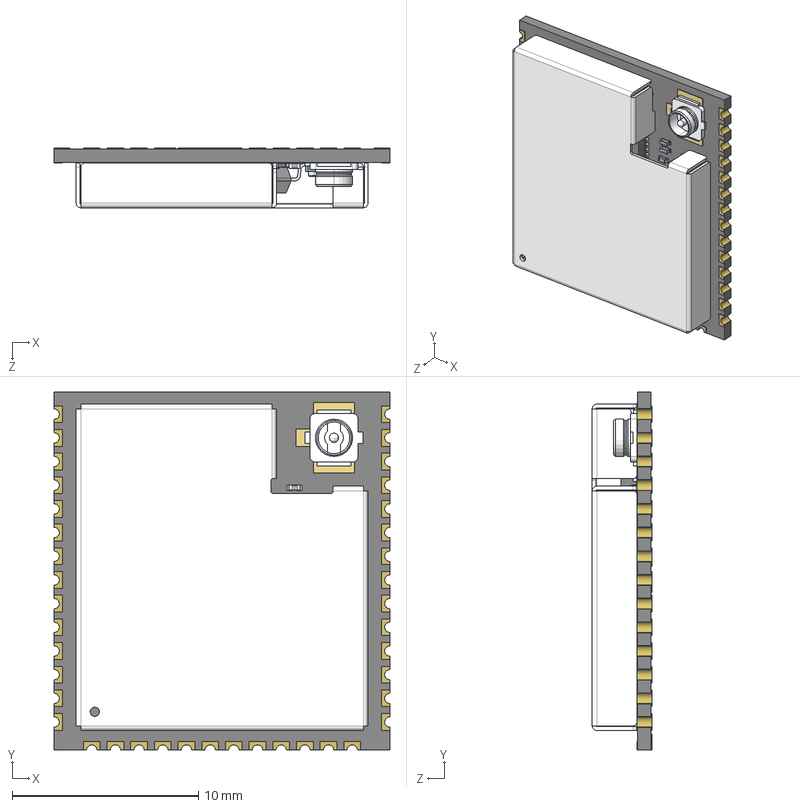
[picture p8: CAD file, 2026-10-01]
3dmodels/ESP32-S3-WROOM-1U.step
18.0 x 19.2 x 3.20 mm
R0201_20210301.STEP^R0201_20210301.STEP_Submodel-R0201_part_DesignRootModel_ESP32-S3-WROOM-1U(2)_ESP32-S3-WROOM-1U_2 x 8
L0201_20210301.STEP^L0201_20210301.STEP_Submodel-L0201_part_DesignRootModel_ESP32-S3-WROOM-1U(2)_ESP32-S3-WROOM-1U_2 x 2
C0201_20210301.STEP^C0201_20210301.STEP_Submodel-C0201_part_DesignRootModel_ESP32-S3-WROOM-1U(2)_ESP32-S3-WROOM-1U_2 x 13
C0402_20210301.STEP^C0402_20210301.STEP_Submodel-C0402_part_DesignRootModel_ESP32-S3-WROOM-1U(2)_ESP32-S3-WROOM-1U_2
I-IPEX.STEP^I-IPEX.STEP_Submodel-IPEX_3P_part_DesignRootModel_ESP32-S3-WROOM-1U(2)_ESP32-S3-WROOM-1U_2
DFN1006.STEP^DFN1006.STEP_Submodel-SOD882_part_DesignRootModel_ESP32-S3-WROOM-1U(2)_ESP32-S3-WROOM-1U_2
SOP8_rev1_20210308.STEP^SOP8_rev1_20210308.STEP_Submodel-SOP8_1P27_6P6_part_DesignRootModel_ESP32-S3-WROOM-1U(2)_ESP32-S3-WROOM-1U_2
ESP32-S3_20210301.STEP^ESP32-S3_20210301.STEP_Submodel-QFN56_0P4_7_part_DesignRootModel_ESP32-S3-WROOM-1U(2)_ESP32-S3-WROOM-1U_2
XTAL3225_20210301.STEP^XTAL3225_20210301.STEP_Submodel-XTAL3225_part_DesignRootModel_ESP32-S3-WROOM-1U(2)_ESP32-S3-WROOM-1U_2
uid__4-111^DesignRootModel_ESP32-S3-WROOM-1U(2)_ESP32-S3-WROOM-1U_2
uid__4-112^DesignRootModel_ESP32-S3-WROOM-1U(2)_ESP32-S3-WROOM-1U_2
uid__4-113^DesignRootModel_ESP32-S3-WROOM-1U(2)_ESP32-S3-WROOM-1U_2
uid__4-130^DesignRootModel_ESP32-S3-WROOM-1U(2)_ESP32-S3-WROOM-1U_2
uid__4-131^DesignRootModel_ESP32-S3-WROOM-1U(2)_ESP32-S3-WROOM-1U_2
uid__4-132^DesignRootModel_ESP32-S3-WROOM-1U(2)_ESP32-S3-WROOM-1U_2
uid__4-148^DesignRootModel_ESP32-S3-WROOM-1U(2)_ESP32-S3-WROOM-1U_2
uid__4-149^DesignRootModel_ESP32-S3-WROOM-1U(2)_ESP32-S3-WROOM-1U_2
uid__4-150^DesignRootModel_ESP32-S3-WROOM-1U(2)_ESP32-S3-WROOM-1U_2
uid__1-253^DesignRootModel_ESP32-S3-WROOM-1U(2)_ESP32-S3-WROOM-1U_2
uid__1-254^DesignRootModel_ESP32-S3-WROOM-1U(2)_ESP32-S3-WROOM-1U_2
uid__1-256^DesignRootModel_ESP32-S3-WROOM-1U(2)_ESP32-S3-WROOM-1U_2
uid__1-257^DesignRootModel_ESP32-S3-WROOM-1U(2)_ESP32-S3-WROOM-1U_2
uid__1-266^DesignRootModel_ESP32-S3-WROOM-1U(2)_ESP32-S3-WROOM-1U_2
uid__1-269^DesignRootModel_ESP32-S3-WROOM-1U(2)_ESP32-S3-WROOM-1U_2
uid__1-270^DesignRootModel_ESP32-S3-WROOM-1U(2)_ESP32-S3-WROOM-1U_2
uid__1-271^DesignRootModel_ESP32-S3-WROOM-1U(2)_ESP32-S3-WROOM-1U_2
uid__1-272^DesignRootModel_ESP32-S3-WROOM-1U(2)_ESP32-S3-WROOM-1U_2
uid__1-273^DesignRootModel_ESP32-S3-WROOM-1U(2)_ESP32-S3-WROOM-1U_2
uid__1-274^DesignRootModel_ESP32-S3-WROOM-1U(2)_ESP32-S3-WROOM-1U_2
uid__1-275^DesignRootModel_ESP32-S3-WROOM-1U(2)_ESP32-S3-WROOM-1U_2
uid__1-276^DesignRootModel_ESP32-S3-WROOM-1U(2)_ESP32-S3-WROOM-1U_2
uid__1-277^DesignRootModel_ESP32-S3-WROOM-1U(2)_ESP32-S3-WROOM-1U_2
uid__1-280^DesignRootModel_ESP32-S3-WROOM-1U(2)_ESP32-S3-WROOM-1U_2
uid__1-292^DesignRootModel_ESP32-S3-WROOM-1U(2)_ESP32-S3-WROOM-1U_2
uid__1-293^DesignRootModel_ESP32-S3-WROOM-1U(2)_ESP32-S3-WROOM-1U_2
uid__1-297^DesignRootModel_ESP32-S3-WROOM-1U(2)_ESP32-S3-WROOM-1U_2
uid__1-300^DesignRootModel_ESP32-S3-WROOM-1U(2)_ESP32-S3-WROOM-1U_2
uid__1-301^DesignRootModel_ESP32-S3-WROOM-1U(2)_ESP32-S3-WROOM-1U_2
uid__1-302^DesignRootModel_ESP32-S3-WROOM-1U(2)_ESP32-S3-WROOM-1U_2
uid__1-303^DesignRootModel_ESP32-S3-WROOM-1U(2)_ESP32-S3-WROOM-1U_2
uid__1-307^DesignRootModel_ESP32-S3-WROOM-1U(2)_ESP32-S3-WROOM-1U_2
uid__1-313^DesignRootModel_ESP32-S3-WROOM-1U(2)_ESP32-S3-WROOM-1U_2
uid__1-319^DesignRootModel_ESP32-S3-WROOM-1U(2)_ESP32-S3-WROOM-1U_2
uid__1-320^DesignRootModel_ESP32-S3-WROOM-1U(2)_ESP32-S3-WROOM-1U_2
uid__1-321^DesignRootModel_ESP32-S3-WROOM-1U(2)_ESP32-S3-WROOM-1U_2
uid__1-328^DesignRootModel_ESP32-S3-WROOM-1U(2)_ESP32-S3-WROOM-1U_2
uid__1-332^DesignRootModel_ESP32-S3-WROOM-1U(2)_ESP32-S3-WROOM-1U_2
uid__1-333^DesignRootModel_ESP32-S3-WROOM-1U(2)_ESP32-S3-WROOM-1U_2
uid__1-334^DesignRootModel_ESP32-S3-WROOM-1U(2)_ESP32-S3-WROOM-1U_2
uid__1-335^DesignRootModel_ESP32-S3-WROOM-1U(2)_ESP32-S3-WROOM-1U_2
uid__1-336^DesignRootModel_ESP32-S3-WROOM-1U(2)_ESP32-S3-WROOM-1U_2
uid__1-337^DesignRootModel_ESP32-S3-WROOM-1U(2)_ESP32-S3-WROOM-1U_2
uid__1-338^DesignRootModel_ESP32-S3-WROOM-1U(2)_ESP32-S3-WROOM-1U_2
uid__1-339^DesignRootModel_ESP32-S3-WROOM-1U(2)_ESP32-S3-WROOM-1U_2
uid__1-340^DesignRootModel_ESP32-S3-WROOM-1U(2)_ESP32-S3-WROOM-1U_2
uid__1-341^DesignRootModel_ESP32-S3-WROOM-1U(2)_ESP32-S3-WROOM-1U_2
uid__1-342^DesignRootModel_ESP32-S3-WROOM-1U(2)_ESP32-S3-WROOM-1U_2
uid__1-343^DesignRootModel_ESP32-S3-WROOM-1U(2)_ESP32-S3-WROOM-1U_2
uid__1-344^DesignRootModel_ESP32-S3-WROOM-1U(2)_ESP32-S3-WROOM-1U_2
uid__1-345^DesignRootModel_ESP32-S3-WROOM-1U(2)_ESP32-S3-WROOM-1U_2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

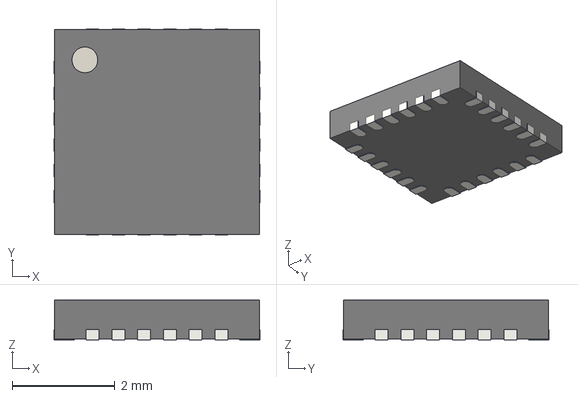
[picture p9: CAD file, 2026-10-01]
3dmodels/InvenSense_QFN-24_4x4mm_P0.5mm.step
4.00 x 4.00 x 0.77 mm

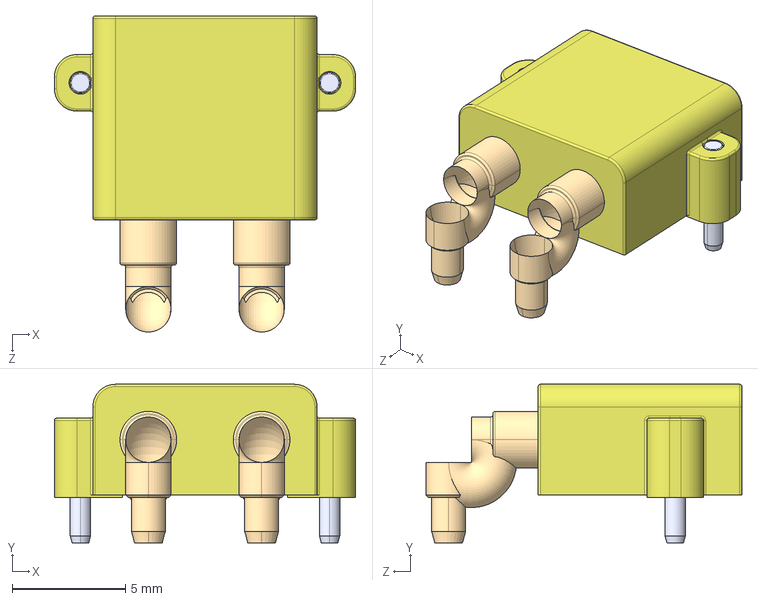
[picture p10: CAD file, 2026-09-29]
3dmodels/AMASS_XT30PW-M_1x02_P2.50mm_Horizontal.step
13.3 x 7.00 x 14.0 mm

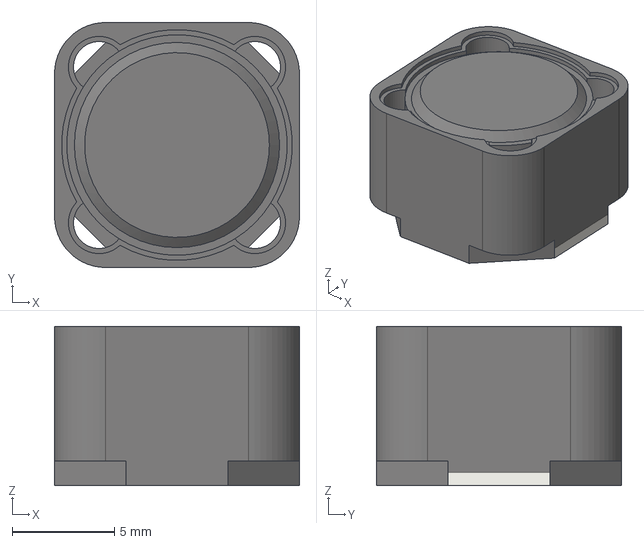
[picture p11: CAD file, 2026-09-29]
3dmodels/L_12x12mm_H8mm.step
12.0 x 12.0 x 7.80 mm

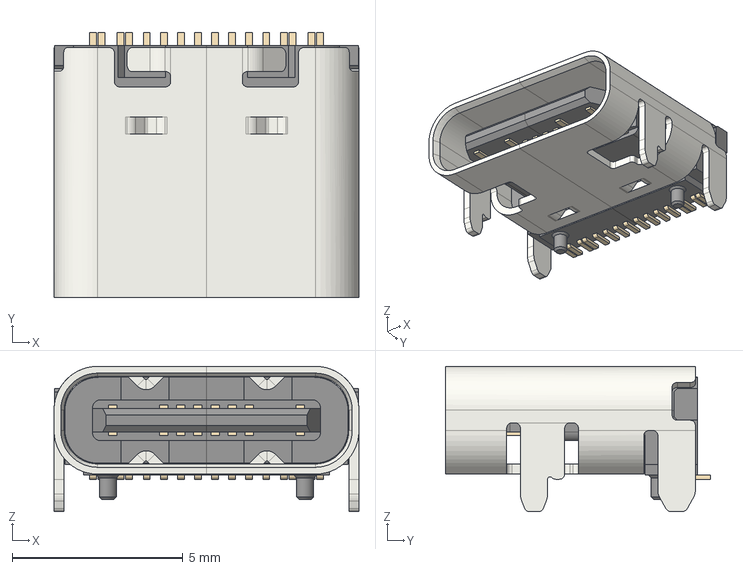
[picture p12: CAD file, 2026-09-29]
3dmodels/USB_C_Receptacle_HCTL_HC-TYPE-C-16P-01A.step
8.94 x 7.78 x 4.26 mm

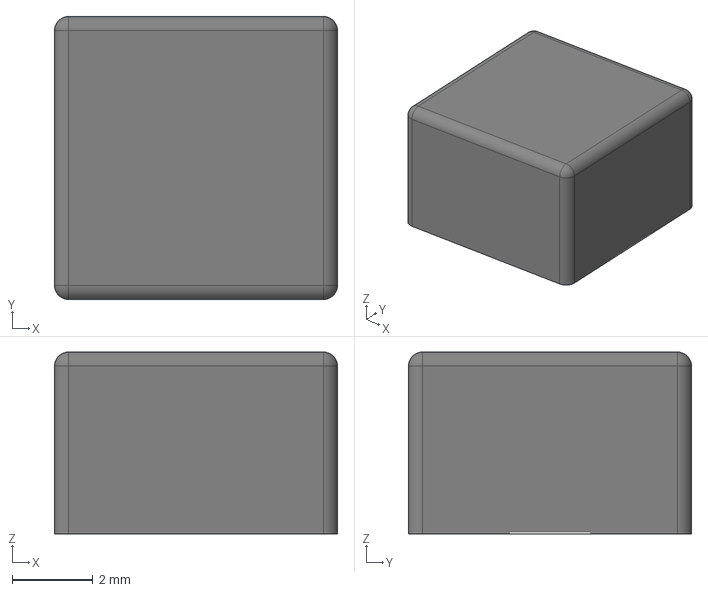
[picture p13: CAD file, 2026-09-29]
3dmodels/L_7.3x7.3_H4.5.step
7.00 x 7.00 x 4.50 mm

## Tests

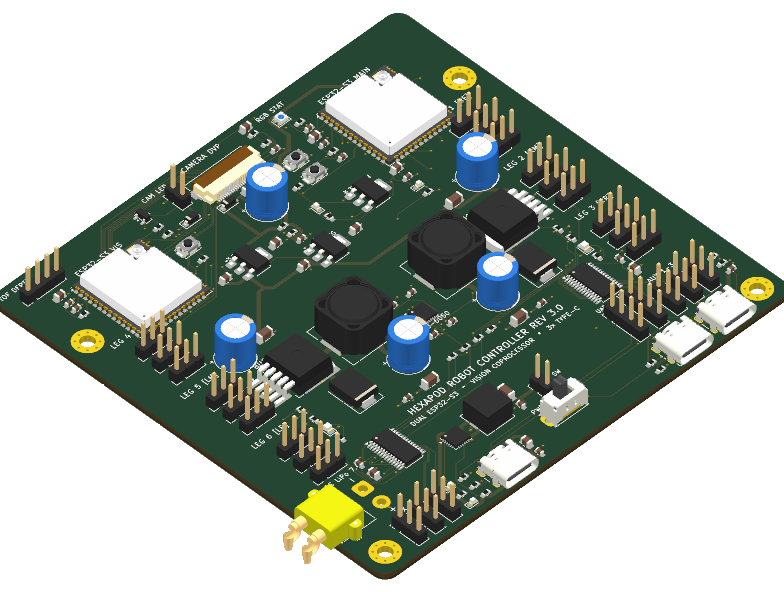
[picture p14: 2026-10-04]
reports/test_local_iso.png

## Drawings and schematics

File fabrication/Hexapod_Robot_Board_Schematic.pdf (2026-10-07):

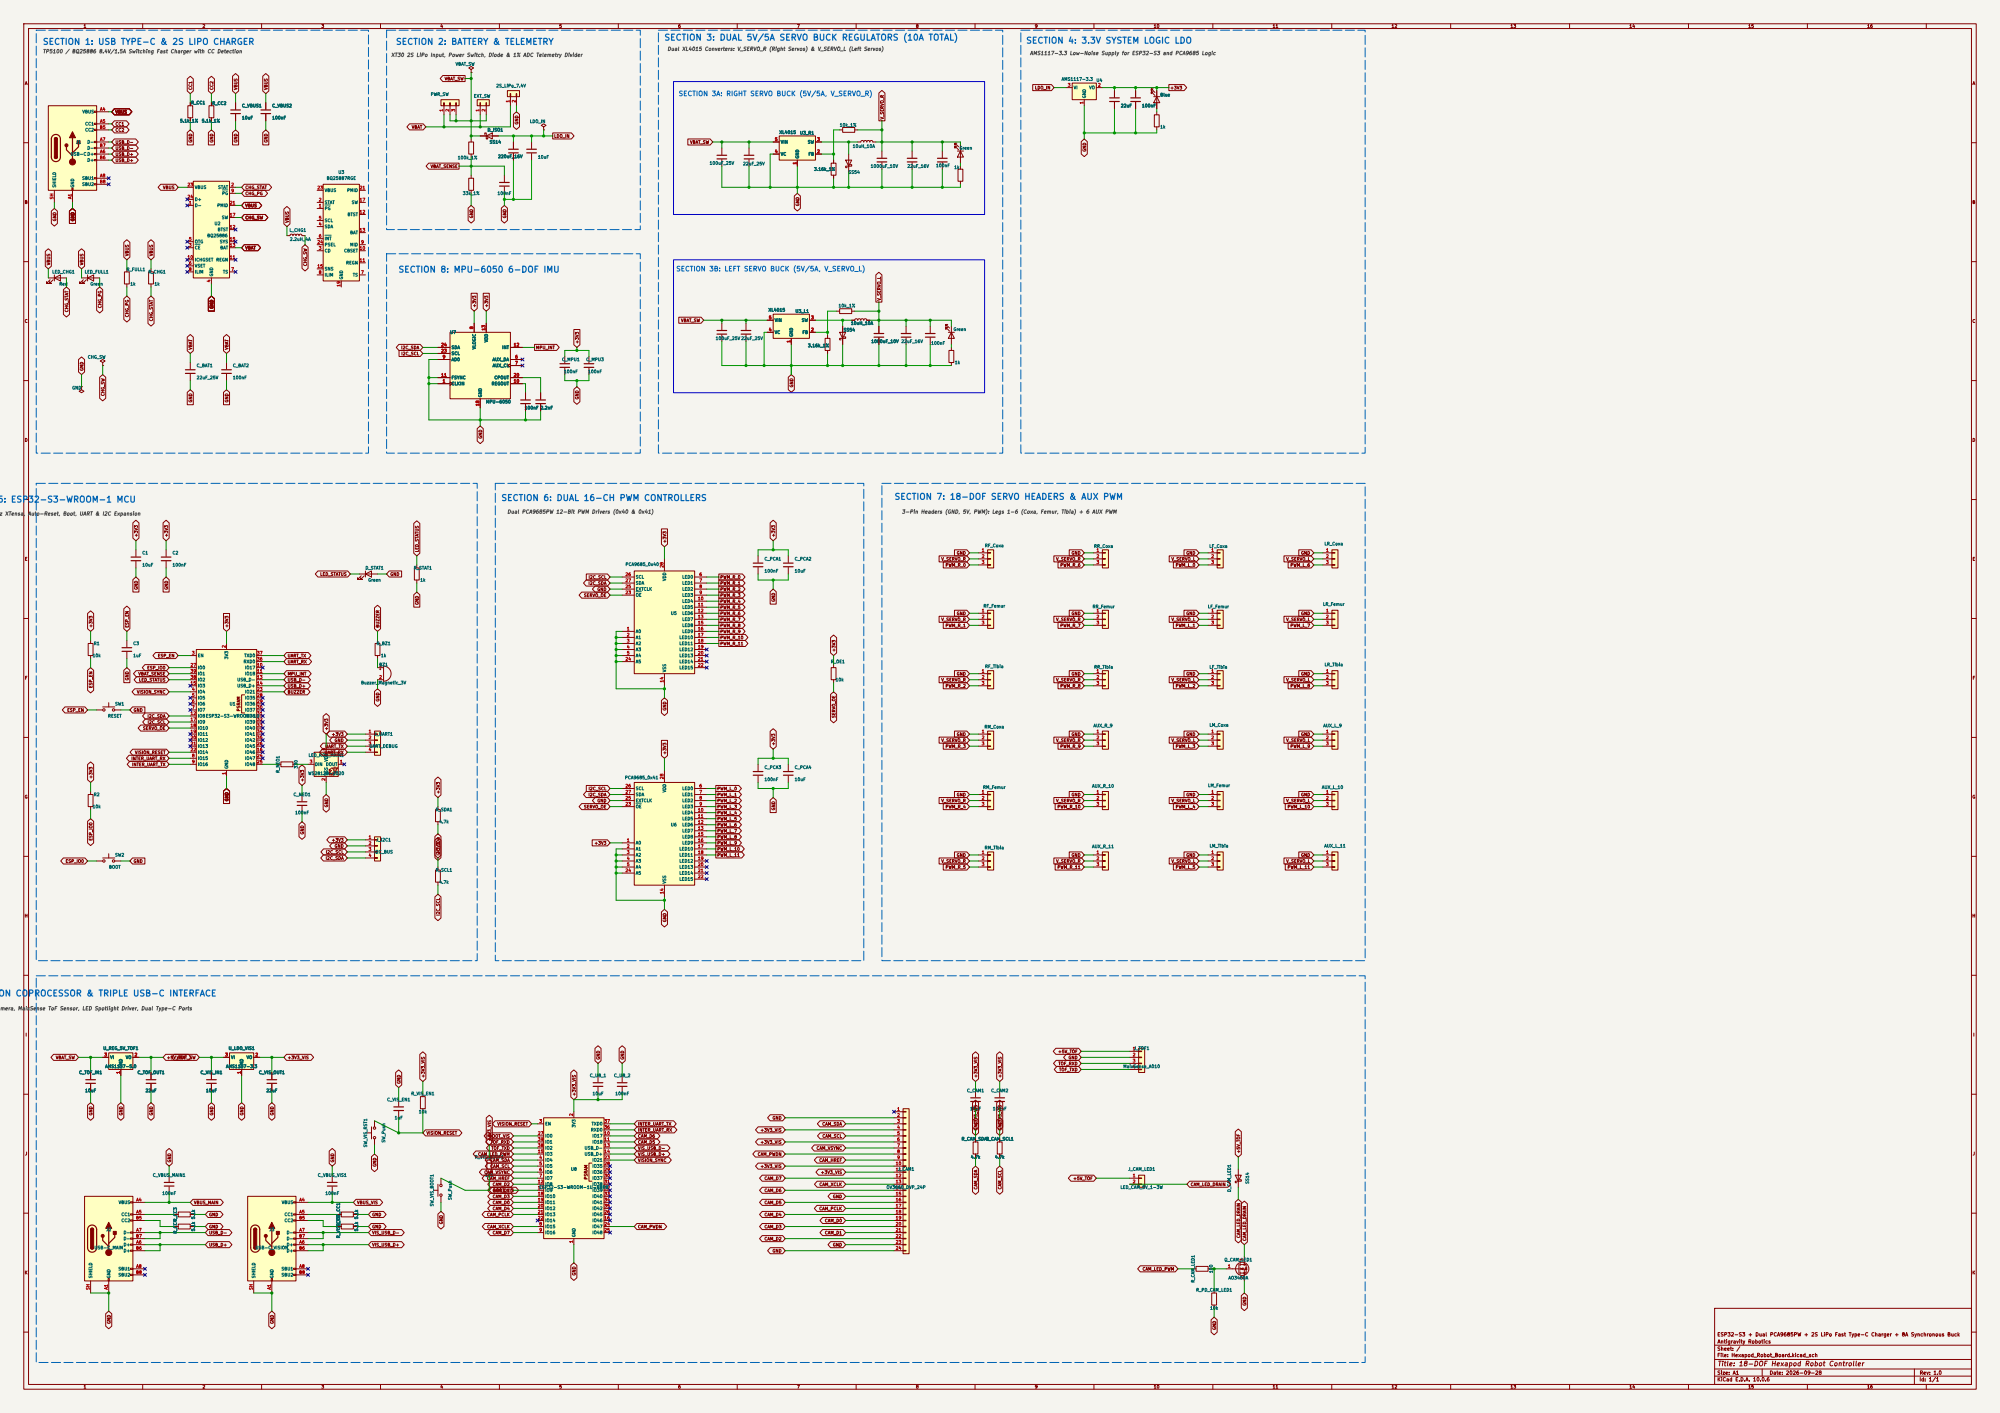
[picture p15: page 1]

SECTION 1: USB TYPE-C & 2S LIPO CHARGER

SECTION 3: DUAL 5V/5A SERVO BUCK REGULATORS (10A TOTAL)

SECTION 4: 3.3V SYSTEM LOGIC LDO

TP5100 / BQ25886 8.4V/1.5A Switching Fast Charger with CC Detection

Dual XL4015 Converters: V_SERVO_R (Right Servos) & V_SERVO_L (Left Servos)

XT30 2S LiPo Input, Power Switch, Diode & 1% ADC Telemetry Divider

AMS1117-3.3 Low-Noise Supply for ESP32-S3 and PCA9685 Logic

SECTION 3A: RIGHT SERVO BUCK (5V/5A, V_SERVO_R)

SECTION 6: DUAL 16-CH PWM CONTROLLERS

SECTION 7: 18-DOF SERVO HEADERS & AUX PWM

Dual-core 240MHz XTensa, Auto-Reset, Boot, UART & I2C Expansion

Dual PCA9685PW 12-Bit PWM Drivers (0x40 & 0x41)

3-Pin Headers (GND, 5V, PWM): Legs 1-6 (Coxa, Femur, Tibia) + 6 AUX PWM

ESP32-S3 + Dual PCA9685PW + 2S LiPo Fast Type-C Charger + 8A Synchronous Buck PSRAM GND 1 3V3 2

SECTION 9: ESP32-S3 VISION COPROCESSOR & TRIPLE USB-C INTERFACE

Dual AMS1117 LDOs, OV3660 DVP Camera, MaixSense ToF Sensor, LED Spotlight Driver, Dual Type-C Ports

Antigravity Robotics
Sheet: /
File: Hexapod_Robot_Board.kicad_sch
Title: 18-DOF Hexapod Robot Controller

Size: A1 | Rev: 1.0
KiCad E.D.A. 10.0.6 | Id: 1/1

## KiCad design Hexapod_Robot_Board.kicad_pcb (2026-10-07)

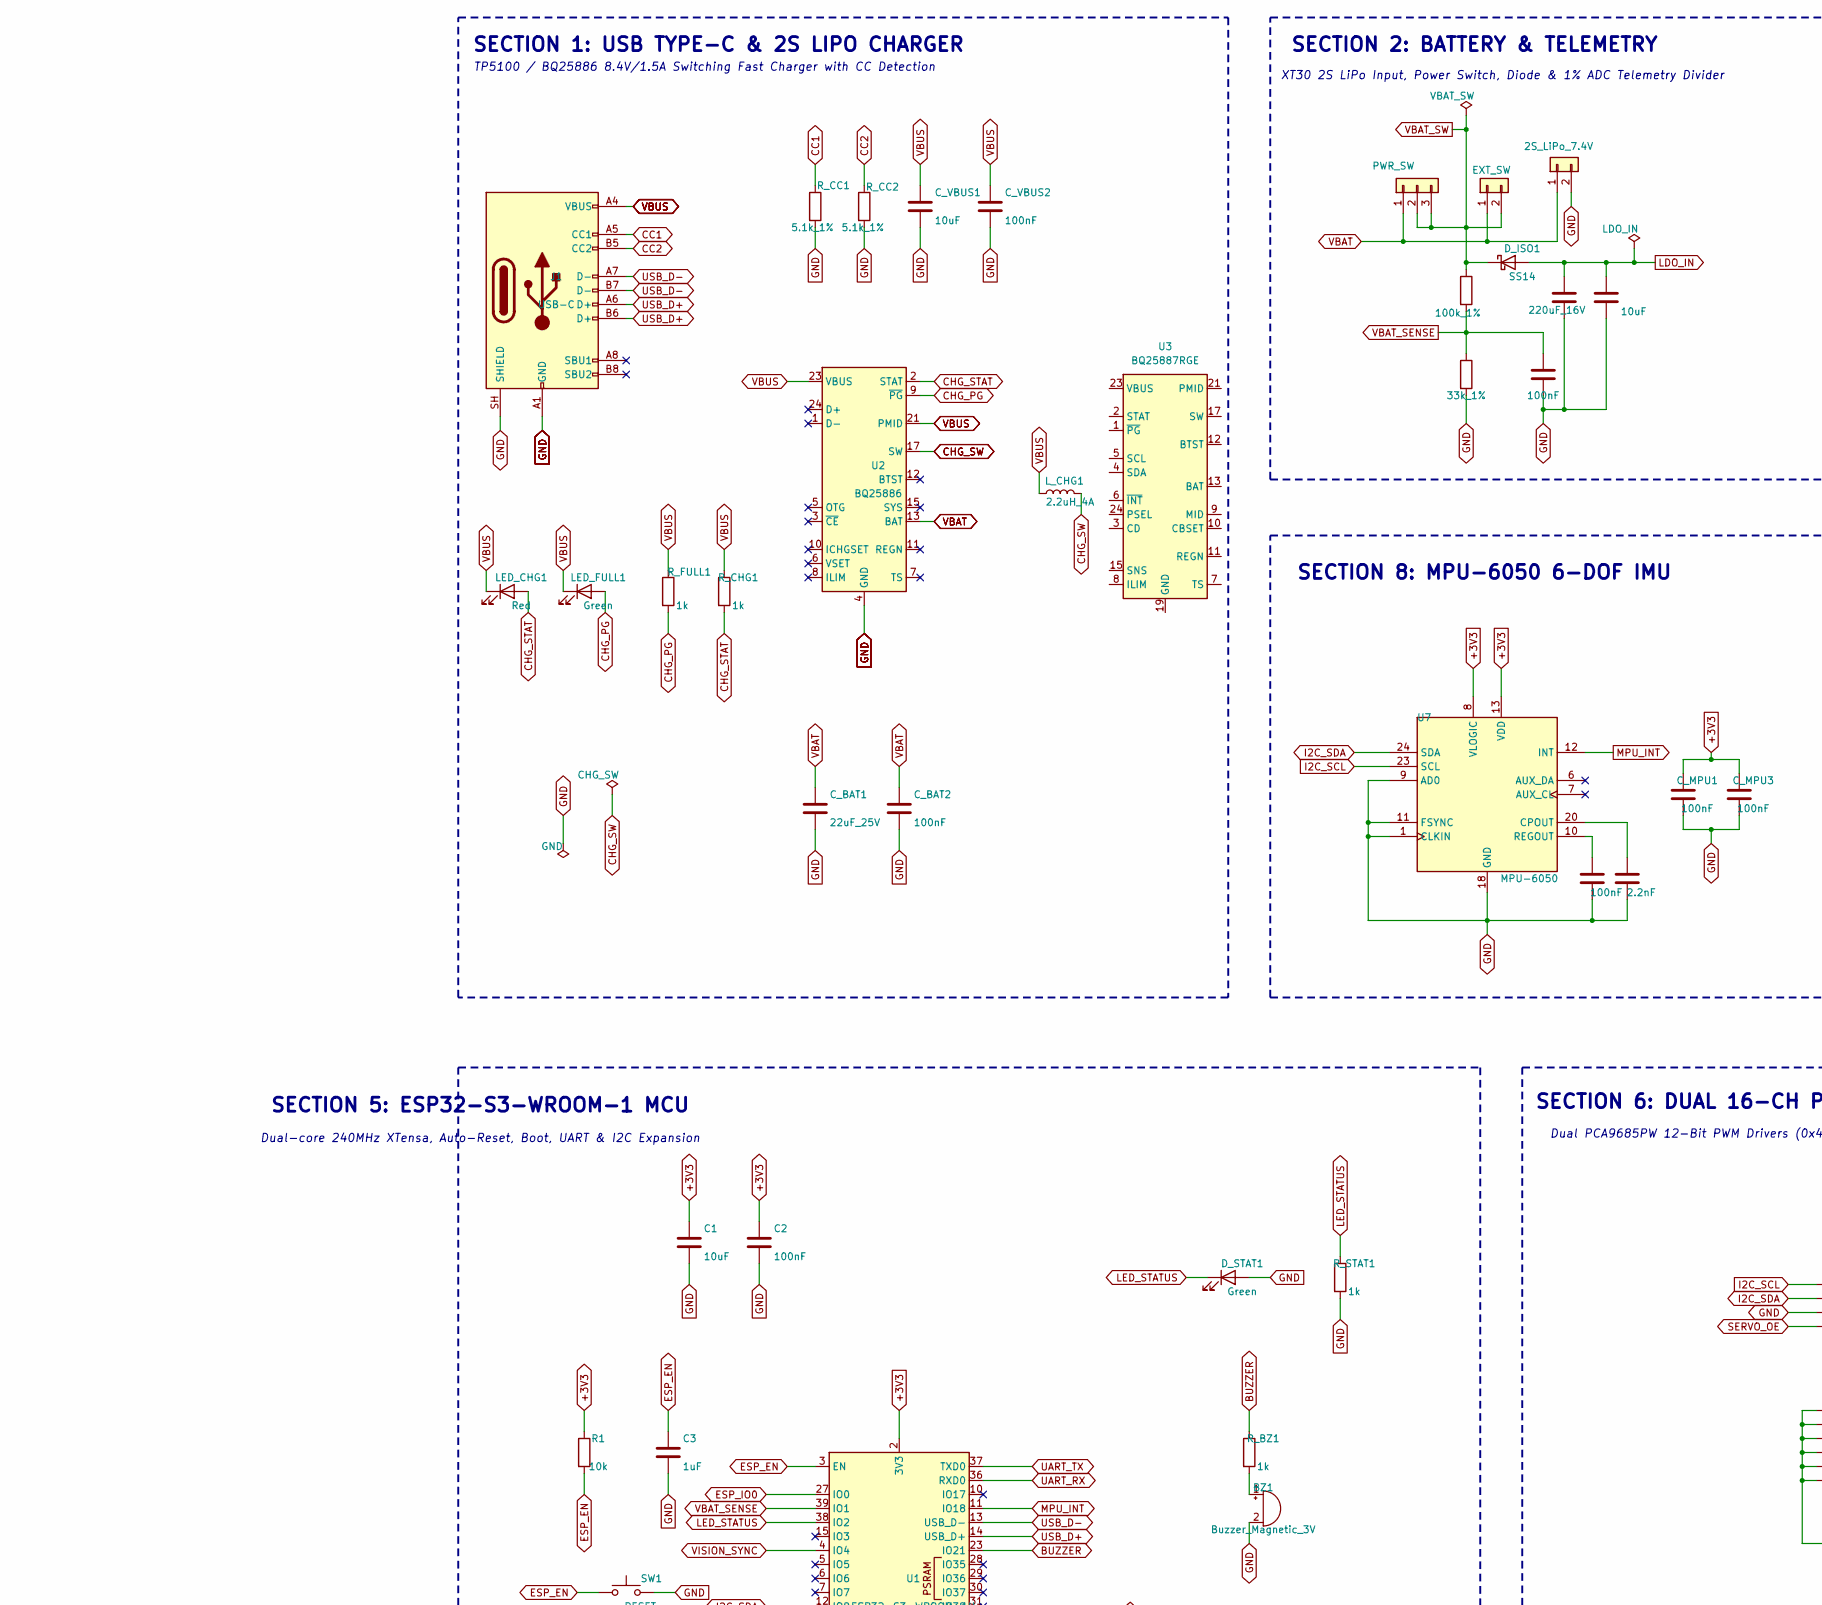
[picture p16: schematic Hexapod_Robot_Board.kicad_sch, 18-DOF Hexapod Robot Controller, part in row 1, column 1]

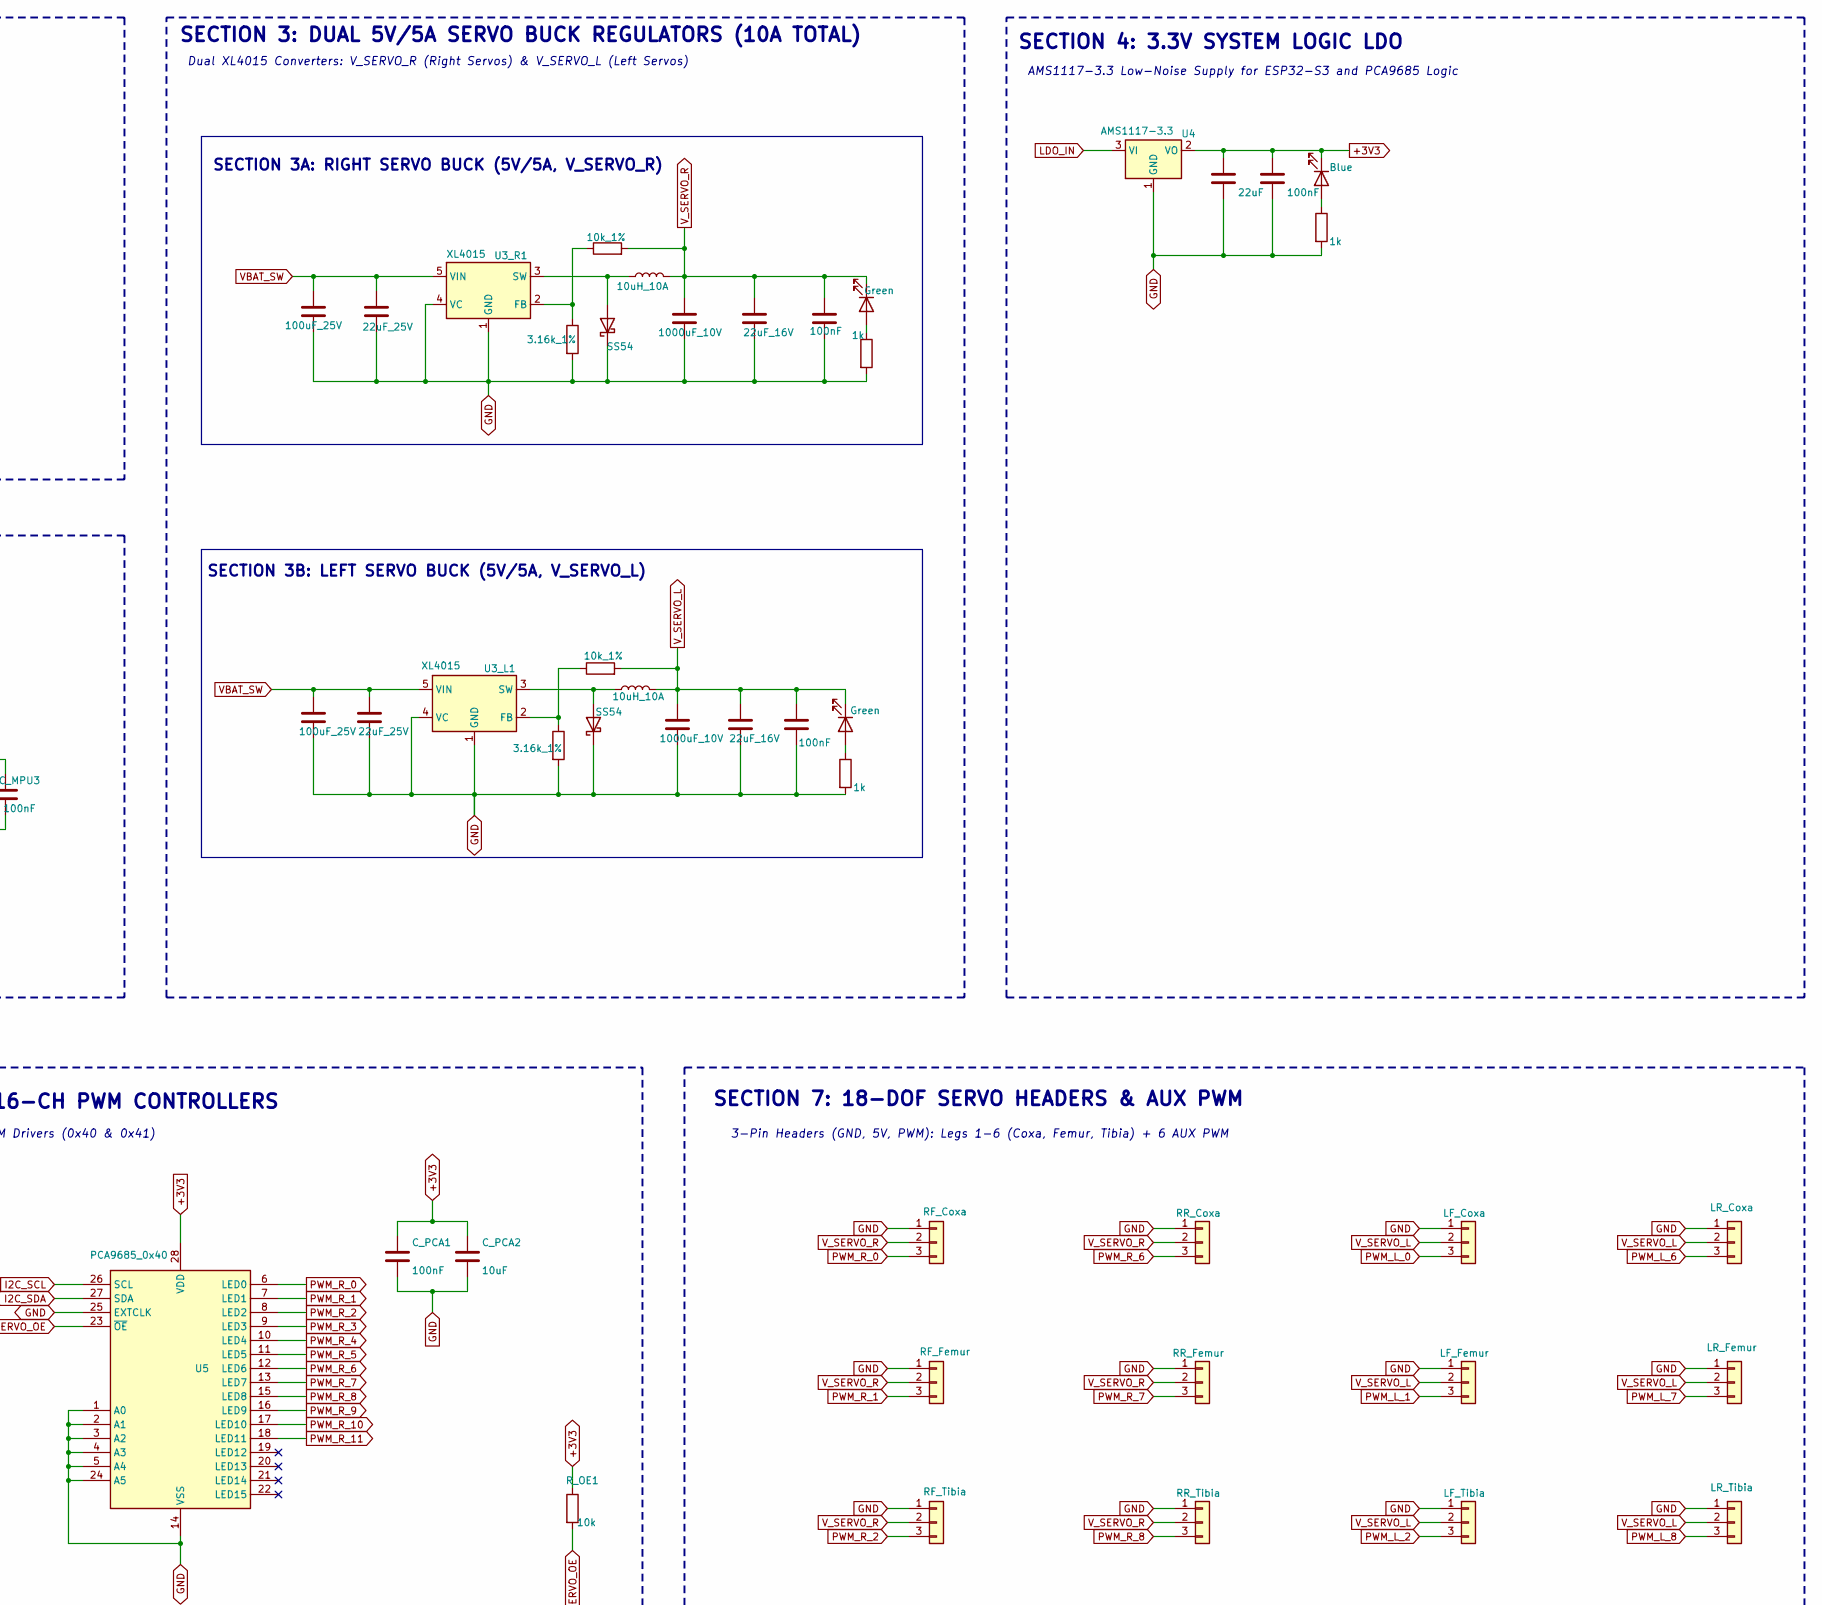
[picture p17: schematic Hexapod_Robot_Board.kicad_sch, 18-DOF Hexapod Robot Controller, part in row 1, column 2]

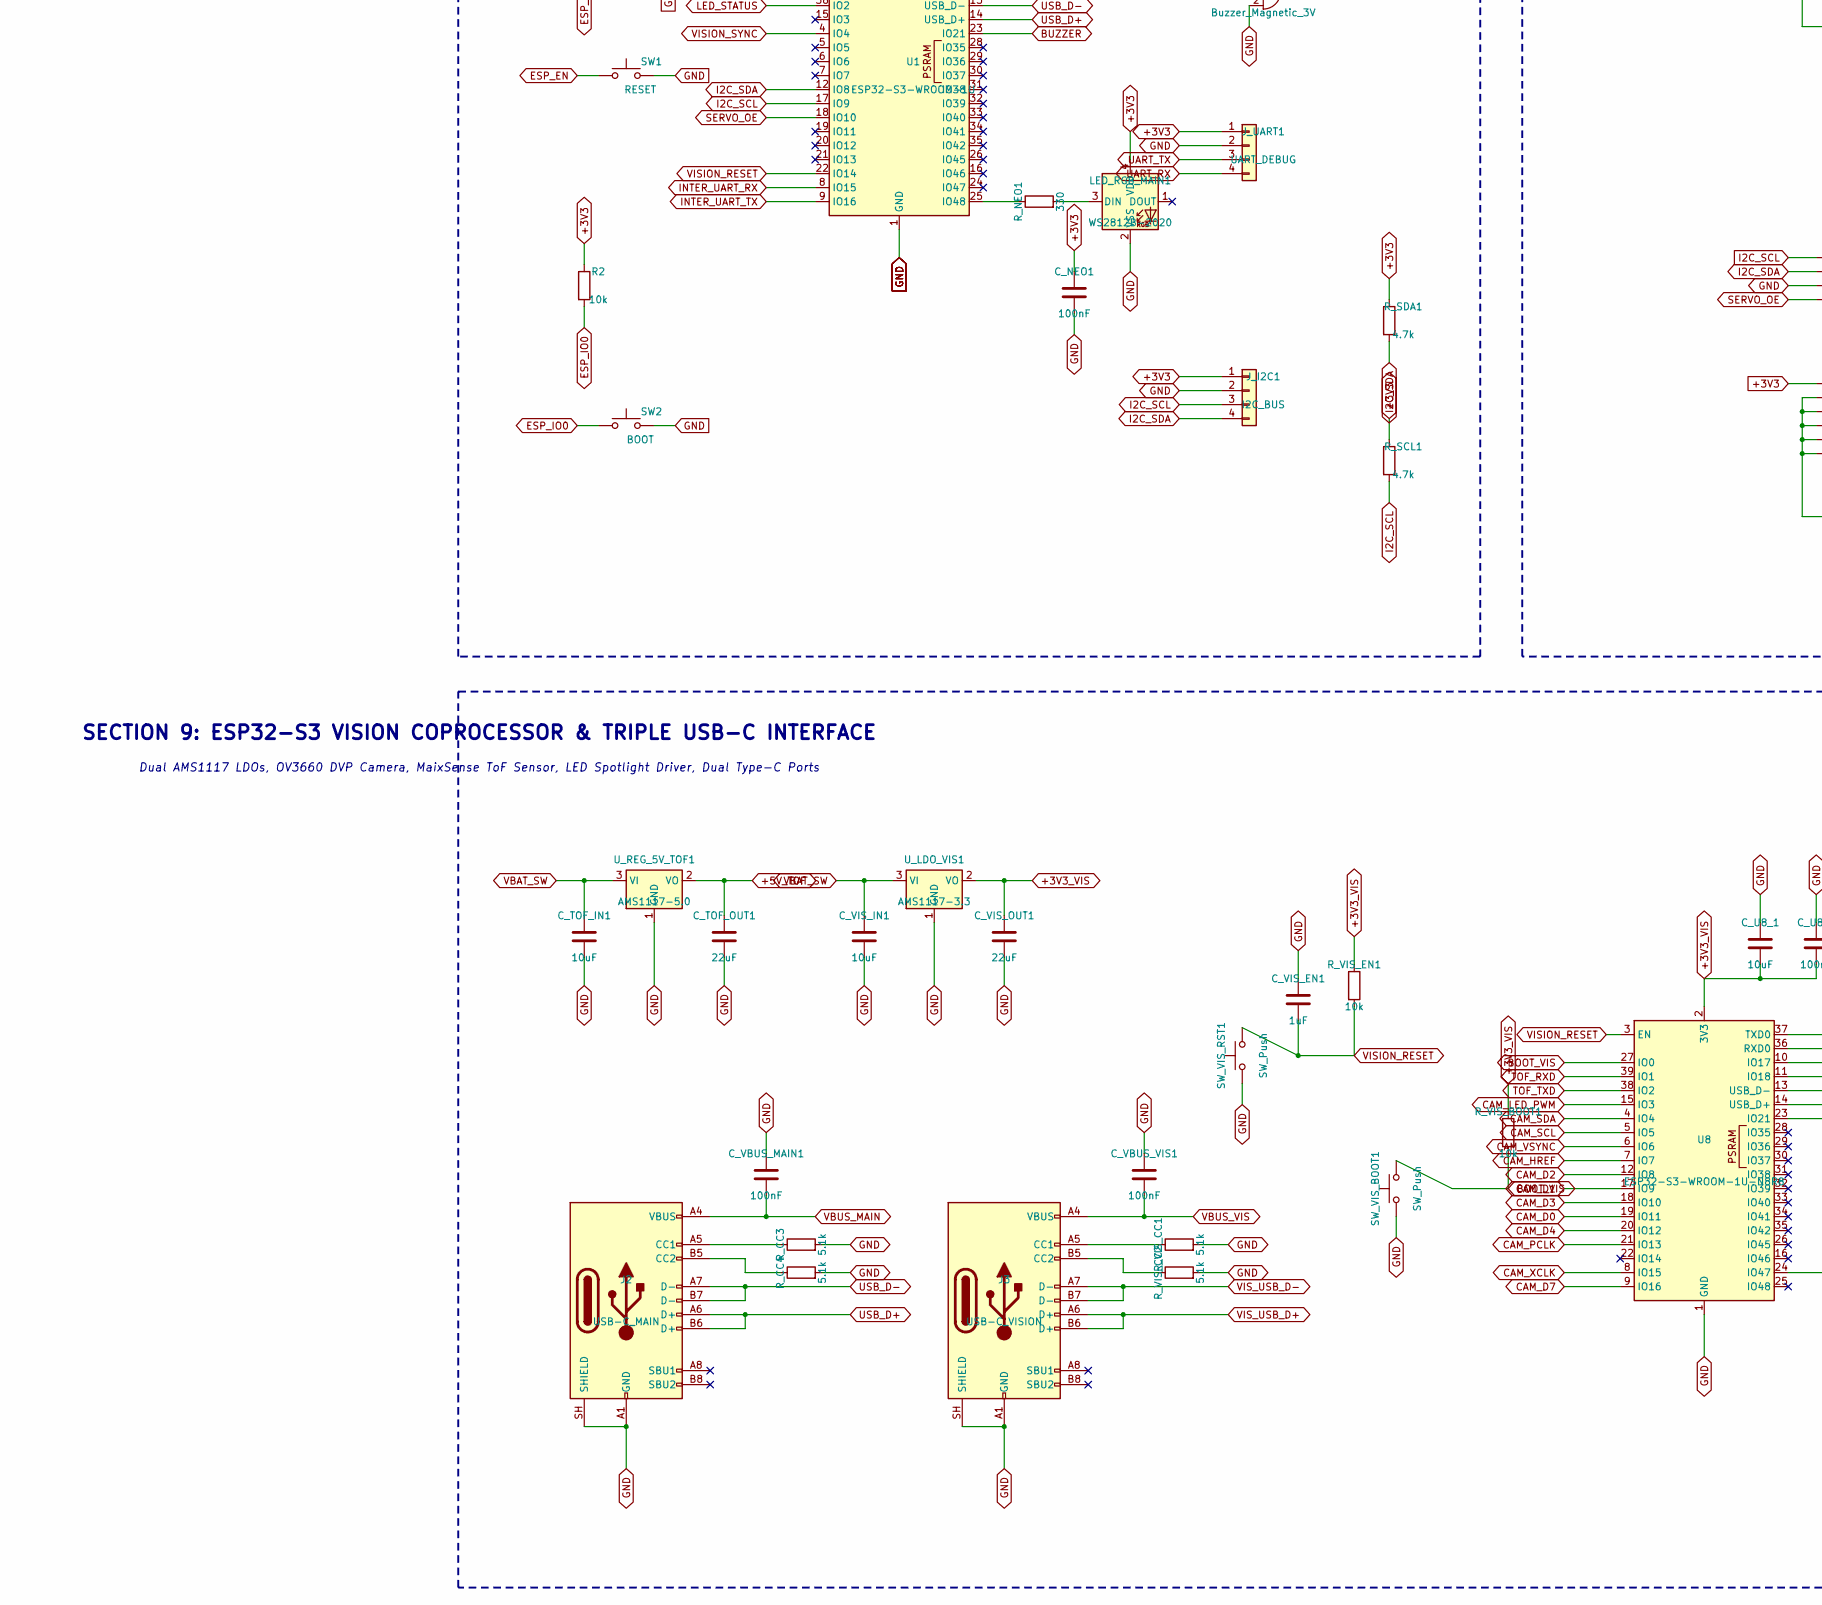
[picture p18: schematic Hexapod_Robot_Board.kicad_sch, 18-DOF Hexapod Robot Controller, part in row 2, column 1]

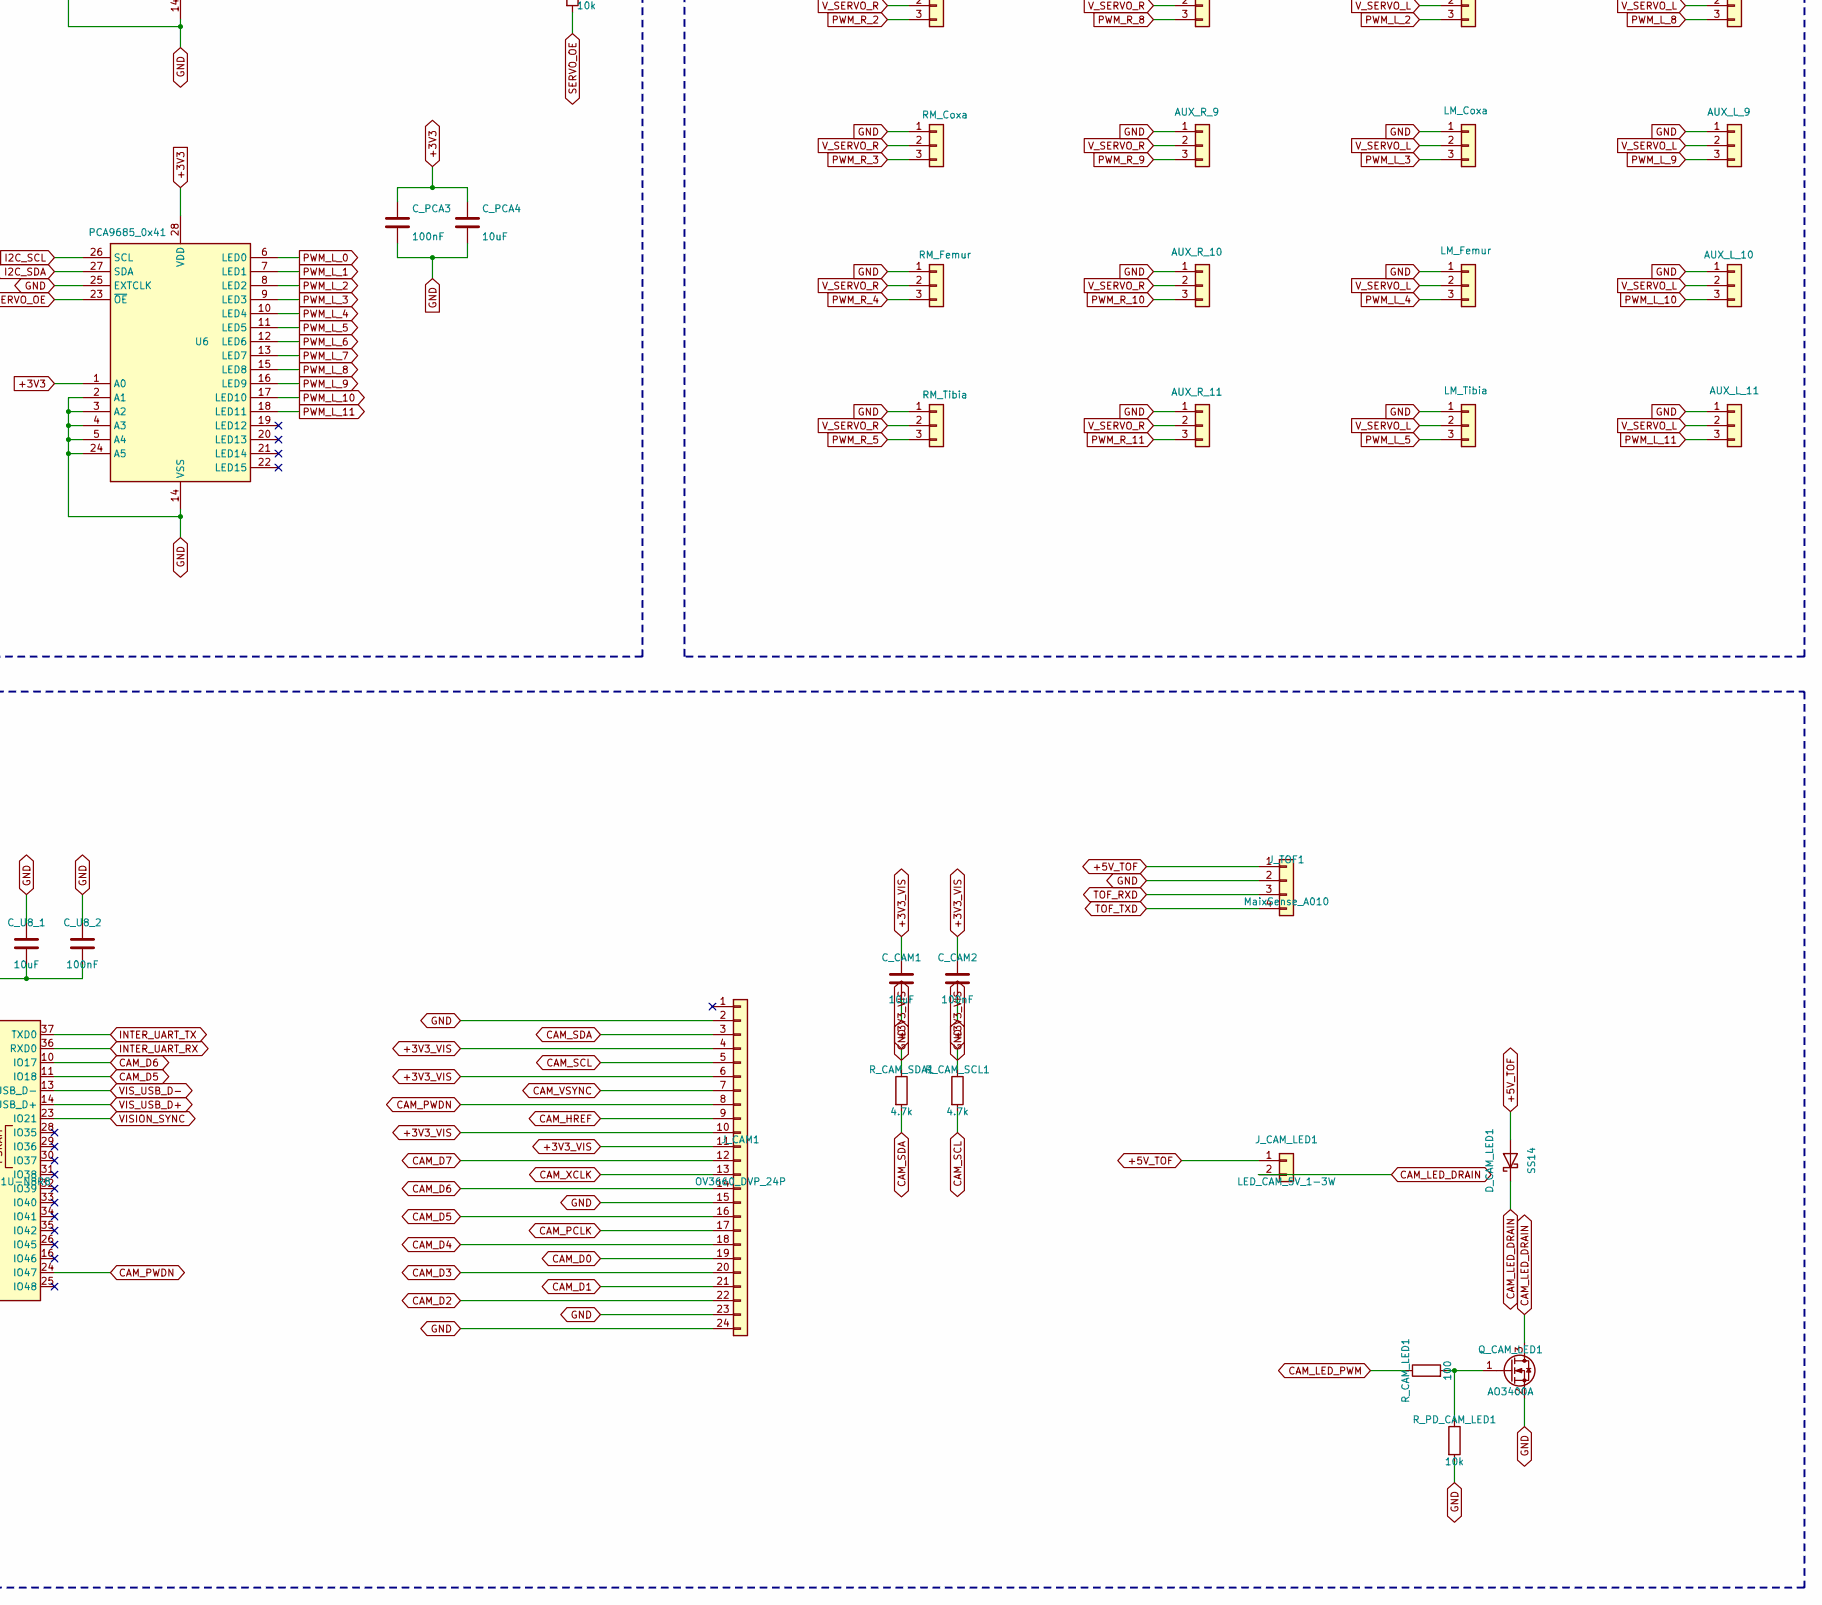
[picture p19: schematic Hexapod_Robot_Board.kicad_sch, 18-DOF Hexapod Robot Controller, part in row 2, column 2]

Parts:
BZ1: Buzzer_Magnetic_3V; MagneticBuzzer_Kingstate_KCG0601
C1: 10uF; C_0805_2012Metric
C2: 100nF; C_0603_1608Metric
C3: 1uF; C_0603_1608Metric
C_3V3_1: 22uF; C_0805_2012Metric
C_3V3_2: 100nF; C_0603_1608Metric
C_BAT1: 22uF_25V; C_1206_3216Metric
C_BAT2: 100nF; C_0603_1608Metric
C_CAM1: 10uF; C_0805_2012Metric
C_CAM2: 100nF; C_0603_1608Metric
C_DIV1: 100nF; C_0603_1608Metric
C_IN1_L1, C_IN1_R1: 100uF_25V; CP_Radial_D8.0mm_P3.50mm
C_IN2_L1, C_IN2_R1: 22uF_25V; C_1206_3216Metric
C_ISO1: 220uF_16V; CP_Radial_D8.0mm_P3.50mm
C_ISO2: 10uF; C_0805_2012Metric
C_MPU1, C_MPU2, C_MPU3: 100nF; C_0603_1608Metric
C_MPU5: 2.2nF; C_0603_1608Metric
C_NEO1: 100nF; C_0603_1608Metric
C_OUT1_L1, C_OUT1_R1: 1000uF_10V; CP_Radial_D8.0mm_P3.50mm
C_OUT2_L1, C_OUT2_R1: 22uF_16V; C_1206_3216Metric
C_OUT3_L1, C_OUT3_R1: 100nF; C_0603_1608Metric
C_PCA1, C_PCA3: 100nF; C_0603_1608Metric
C_PCA2, C_PCA4: 10uF; C_0805_2012Metric
C_TOF_IN1: 10uF; C_0805_2012Metric
C_TOF_OUT1: 22uF; C_0805_2012Metric
C_U8_1: 10uF; C_0805_2012Metric
C_U8_2: 100nF; C_0603_1608Metric
C_VBUS1: 10uF; C_0805_2012Metric
C_VBUS2: 100nF; C_0603_1608Metric
C_VBUS_MAIN1: 100nF; C_0603_1608Metric
C_VBUS_VIS1: 100nF; C_0603_1608Metric
C_VIS_EN1: 1uF; C_0603_1608Metric
C_VIS_IN1: 10uF; C_0805_2012Metric
C_VIS_OUT1: 22uF; C_0805_2012Metric
D_CAM_LED1: SS14; D_SOD-123
D_CATCH_L1: SS54; D_SMC
D_CATCH_R1: SS54; D_SMC
D_ISO1: SS14; D_SOD-123
D_STAT1: Green; LED_0603_1608Metric
J1: USB-C; USB_C_Receptacle_HCTL_HC-TYPE-C-16P-01A
J2: USB-C_MAIN; USB_C_Receptacle_HCTL_HC-TYPE-C-16P-01A
J3: USB-C_VISION; USB_C_Receptacle_HCTL_HC-TYPE-C-16P-01A
J_AUX1: AUX_R_9; PinHeader_1x03_P2.54mm_Vertical
J_AUX2: AUX_R_10; PinHeader_1x03_P2.54mm_Vertical
J_AUX3: AUX_R_11; PinHeader_1x03_P2.54mm_Vertical
J_AUX4: AUX_L_9; PinHeader_1x03_P2.54mm_Vertical
J_AUX5: AUX_L_10; PinHeader_1x03_P2.54mm_Vertical
J_AUX6: AUX_L_11; PinHeader_1x03_P2.54mm_Vertical
J_BAT1: 2S_LiPo_7.4V; AMASS_XT30PW-M_1x02_P2.50mm_Horizontal
J_CAM1: OV3660_DVP_24P; Hirose_FH12-24S-0.5SH_1x24-1MP_P0.50mm_Horizontal
J_CAM_LED1: LED_CAM_5V_1-3W; PinHeader_1x02_P2.54mm_Vertical
J_I2C1: I2C_BUS; PinHeader_1x04_P2.54mm_Vertical
J_L1_C1: RF_Coxa; PinHeader_1x03_P2.54mm_Vertical
J_L1_F1: RF_Femur; PinHeader_1x03_P2.54mm_Vertical
J_L1_T1: RF_Tibia; PinHeader_1x03_P2.54mm_Vertical
J_L2_C1: RM_Coxa; PinHeader_1x03_P2.54mm_Vertical
J_L2_F1: RM_Femur; PinHeader_1x03_P2.54mm_Vertical
J_L2_T1: RM_Tibia; PinHeader_1x03_P2.54mm_Vertical
J_L3_C1: RR_Coxa; PinHeader_1x03_P2.54mm_Vertical
J_L3_F1: RR_Femur; PinHeader_1x03_P2.54mm_Vertical
J_L3_T1: RR_Tibia; PinHeader_1x03_P2.54mm_Vertical
J_L4_C1: LF_Coxa; PinHeader_1x03_P2.54mm_Vertical
J_L4_F1: LF_Femur; PinHeader_1x03_P2.54mm_Vertical
J_L4_T1: LF_Tibia; PinHeader_1x03_P2.54mm_Vertical
J_L5_C1: LM_Coxa; PinHeader_1x03_P2.54mm_Vertical
J_L5_F1: LM_Femur; PinHeader_1x03_P2.54mm_Vertical
J_L5_T1: LM_Tibia; PinHeader_1x03_P2.54mm_Vertical
J_L6_C1: LR_Coxa; PinHeader_1x03_P2.54mm_Vertical
J_L6_F1: LR_Femur; PinHeader_1x03_P2.54mm_Vertical
J_L6_T1: LR_Tibia; PinHeader_1x03_P2.54mm_Vertical
J_SW_EXT1: EXT_SW; PinHeader_1x02_P2.54mm_Vertical
J_TOF1: MaixSense_A010; PinHeader_1x04_P2.54mm_Vertical
J_UART1: UART_DEBUG; PinHeader_1x04_P2.54mm_Vertical
LED_3V3: Blue; LED_0603_1608Metric
LED_CHG1: Red; LED_0603_1608Metric
LED_FULL1: Green; LED_0603_1608Metric
LED_L1: Green; LED_0805_2012Metric
LED_R1: Green; LED_0805_2012Metric
LED_RGB_MAIN1: WS2812B-2020; LED_WS2812B-2020_PLCC4_2.0x2.0mm
L_CHG1: 2.2uH_4A; L_7.3x7.3_H4.5
L_SERVO_L1: 10uH_10A; L_12x12mm_H8mm
L_SERVO_R1: 10uH_10A; L_12x12mm_H8mm
Q_CAM_LED1: AO3400A; SOT-23
R1, R2: 10k; R_0603_1608Metric
R_3V3_LED1: 1k; R_0603_1608Metric
R_BZ1: 1k; R_0603_1608Metric
R_CAM_LED1: 100; R_0603_1608Metric
R_CAM_SCL1: 4.7k; R_0603_1608Metric
R_CAM_SDA1: 4.7k; R_0603_1608Metric
R_CC1, R_CC2: 5.1k_1%; R_0603_1608Metric
R_CC3, R_CC4: 5.1k; R_0603_1608Metric
R_CHG1: 1k; R_0603_1608Metric
R_DIV1: 100k_1%; R_0603_1608Metric
R_DIV2: 33k_1%; R_0603_1608Metric
R_FB1_L1, R_FB1_R1: 10k_1%; R_0603_1608Metric
R_FB2_L1, R_FB2_R1: 3.16k_1%; R_0603_1608Metric
R_FULL1: 1k; R_0603_1608Metric
R_LED_L1: 1k; R_0603_1608Metric
R_LED_R1: 1k; R_0603_1608Metric
R_NEO1: 330; R_0603_1608Metric
R_OE1: 10k; R_0603_1608Metric
R_PD_CAM_LED1: 10k; R_0603_1608Metric
R_SCL1: 4.7k; R_0603_1608Metric
R_SDA1: 4.7k; R_0603_1608Metric
R_STAT1: 1k; R_0603_1608Metric
R_VIS_BOOT1: 10k; R_0603_1608Metric
R_VIS_CC1, R_VIS_CC2: 5.1k; R_0603_1608Metric
R_VIS_EN1: 10k; R_0603_1608Metric
SW1: RESET; SW_Push_SPST_NO_Alps_SKRK
SW2: BOOT; SW_Push_SPST_NO_Alps_SKRK
SW_PWR1: PWR_SW; SW_Slide_SPDT_Straight_CK_OS102011MS2Q
SW_VIS_BOOT1: SW_Push; SW_Push_SPST_NO_Alps_SKRK
SW_VIS_RST1: SW_Push; SW_Push_SPST_NO_Alps_SKRK
U1: ESP32-S3-WROOM-1U
U2: BQ25886; QFN-24-1EP_4x4mm_P0.5mm_EP2.7x2.7mm_ThermalVias
U3: BQ25887RGE; Texas_RGE0024H_VQFN-24-1EP_4x4mm_P0.5mm_EP2.7x2.7mm_Thermal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
U3_L1, U3_R1: XL4015; TO-263-5_TabPin3
U4: AMS1117-3.3; SOT-223-3_TabPin2
U5: PCA9685_0x40; TSSOP-28_4.4x9.7mm_P0.65mm
U6: PCA9685_0x41; TSSOP-28_4.4x9.7mm_P0.65mm
U7: MPU-6050; InvenSense_QFN-24_4x4mm_P0.5mm
U8: ESP32-S3-WROOM-1U-N8R8; ESP32-S3-WROOM-1U
U_LDO_VIS1: AMS1117-3.3; SOT-223-3_TabPin2
U_REG_5V_TOF1: AMS1117-5.0; SOT-223-3_TabPin2

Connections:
+3V3: C1.1, C2.1, C_3V3_1.1, C_3V3_2.1, C_MPU1.1, C_MPU3.1, C_NEO1.1, C_PCA1.1, C_PCA2.1, C_PCA3.1, C_PCA4.1, J_I2C1.1, J_UART1.1, LED_3V3.1 (K), LED_RGB_MAIN1.4 (VDD), R1.1, R2.1, R_OE1.1, R_SCL1.1, R_SDA1.1, U1.2 (3V3), U4.2 (VO), U5.28 (VDD), U6.1 (A0), U6.28 (VDD), U7.8 (VLOGIC), U7.13 (VDD)
+3V3_VIS: C_CAM1.1, C_CAM2.1, C_U8_1.2, C_U8_2.2, C_VIS_OUT1.1, J_CAM1.4, J_CAM1.6, J_CAM1.10, J_CAM1.11, R_CAM_SCL1.1, R_CAM_SDA1.1, R_VIS_BOOT1.1, R_VIS_EN1.1, U8.2 (3V3), U_LDO_VIS1.2 (VO)
+5V_TOF: C_TOF_OUT1.1, D_CAM_LED1.2 (A), J_CAM_LED1.1, J_TOF1.1, U_REG_5V_TOF1.2 (VO)
BOOT_VIS: R_VIS_BOOT1.2, SW_VIS_BOOT1.2, U8.27 (IO0)
BUZZER: R_BZ1.1, U1.23 (IO21)
CAM_D0: J_CAM1.19, U8.19 (IO11)
CAM_D1: J_CAM1.21, U8.17 (IO9)
CAM_D2: J_CAM1.22, U8.12 (IO8)
CAM_D3: J_CAM1.20, U8.18 (IO10)
CAM_D4: J_CAM1.18, U8.20 (IO12)
CAM_D5: J_CAM1.16, U8.11 (IO18)
CAM_D6: J_CAM1.14, U8.10 (IO17)
CAM_D7: J_CAM1.12, U8.9 (IO16)
CAM_HREF: J_CAM1.9, U8.7 (IO7)
CAM_LED_DRAIN: D_CAM_LED1.1 (K), J_CAM_LED1.2, Q_CAM_LED1.3 (D)
CAM_LED_PWM: R_CAM_LED1.1, U8.15 (IO3)
CAM_PCLK: J_CAM1.17, U8.21 (IO13)
CAM_PWDN: J_CAM1.8, U8.24 (IO47)
CAM_SCL: J_CAM1.5, R_CAM_SCL1.2, U8.5 (IO5)
CAM_SDA: J_CAM1.3, R_CAM_SDA1.2, U8.4 (IO4)
CAM_VSYNC: J_CAM1.7, U8.6 (IO6)
CAM_XCLK: J_CAM1.13, U8.8 (IO15)
CC1: J1.A5 (CC1), R_CC1.1
CC2: J1.B5 (CC2), R_CC2.1
CHG_PG: LED_FULL1.2 (A), R_FULL1.2, U2.9 (~PG)
CHG_STAT: LED_CHG1.2 (A), R_CHG1.2, U2.2 (STAT)
CHG_SW: L_CHG1.2, U2.17 (SW), U2.18 (SW)
ESP_EN: C3.1, R1.2, SW1.1, U1.3 (EN)
ESP_IO0: R2.2, SW2.1, U1.27 (IO0)
GND: BZ1.2 (-), C1.2, C2.2, C3.2, C_3V3_1.2, C_3V3_2.2, C_BAT1.2, C_BAT2.2, C_CAM1.2, C_CAM2.2, C_DIV1.2, C_IN1_L1.2, C_IN1_R1.2, C_IN2_L1.2, C_IN2_R1.2, C_ISO1.2, C_ISO2.2, C_MPU1.2, C_MPU2.2, C_MPU3.2, C_MPU5.2, C_NEO1.2, C_OUT1_L1.2, C_OUT1_R1.2, C_OUT2_L1.2, C_OUT2_R1.2, C_OUT3_L1.2, C_OUT3_R1.2, C_PCA1.2, C_PCA2.2, C_PCA3.2, C_PCA4.2, C_TOF_IN1.2, C_TOF_OUT1.2, C_U8_1.1, C_U8_2.1, C_VBUS1.2, C_VBUS2.2, C_VBUS_MAIN1.1, C_VBUS_VIS1.1, C_VIS_EN1.1, C_VIS_IN1.2, C_VIS_OUT1.2, D_CATCH_L1.1 (K), D_CATCH_R1.1 (K), D_STAT1.2 (A), J1.A1 (GND), J1.A12 (GND), J1.B1 (GND), J1.B12 (GND), J1.SH (SHIELD), J2.A1 (GND), J2.A12 (GND), J2.B1 (GND), J2.B12 (GND), J2.SH (SHIELD), J3.A1 (GND), J3.A12 (GND), J3.B1 (GND), J3.B12 (GND), J3.SH (SHIELD), J_AUX1.1, J_AUX2.1, J_AUX3.1, J_AUX4.1, J_AUX5.1, J_AUX6.1, J_BAT1.2, J_CAM1.2, J_CAM1.15, J_CAM1.23, J_CAM1.24, J_I2C1.2, J_L1_C1.1, J_L1_F1.1, J_L1_T1.1, J_L2_C1.1, J_L2_F1.1, J_L2_T1.1, J_L3_C1.1, J_L3_F1.1, J_L3_T1.1, J_L4_C1.1, J_L4_F1.1, J_L4_T1.1, J_L5_C1.1, J_L5_F1.1, J_L5_T1.1, J_L6_C1.1, J_L6_F1.1, J_L6_T1.1, J_TOF1.2, J_UART1.2, LED_RGB_MAIN1.2 (VSS), Q_CAM_LED1.2 (S), R_3V3_LED1.2, R_CC1.2, R_CC2.2, R_CC3.2, R_CC4.2, R_DIV2.2, R_FB2_L1.2, R_FB2_R1.2, R_LED_L1.2, R_LED_R1.2, R_PD_CAM_LED1.2, R_STAT1.2, R_VIS_CC1.2, R_VIS_CC2.2, SW1.2, SW2.2, SW_VIS_BOOT1.1, SW_VIS_RST1.1, U1.1 (GND), U1.40 (GND), U1.41 (GND), U2.4 (GND), U2.19 (GND), U2.20 (GND), U2.25 (GND), U3_L1.1 (GND), U3_L1.4 (VC), U3_R1.1 (GND), U3_R1.4 (VC), U4.1 (GND), U5.1 (A0), U5.2 (A1), U5.3 (A2), U5.4 (A3), U5.5 (A4), U5.14 (VSS), U5.24 (A5), U5.25 (EXTCLK), U6.2 (A1), U6.3 (A2), U6.4 (A3), U6.5 (A4), U6.14 (VSS), U6.24 (A5), U6.25 (EXTCLK), U7.1 (CLKIN), U7.9 (AD0), U7.11 (FSYNC), U7.18 (GND), U8.1 (GND), U8.40 (GND), U8.41 (GND), U_LDO_VIS1.1 (GND), U_REG_5V_TOF1.1 (GND)
I2C_SCL: J_I2C1.3, R_SCL1.2, U1.17 (IO9), U5.26 (SCL), U6.26 (SCL), U7.23 (SCL)
I2C_SDA: J_I2C1.4, R_SDA1.2, U1.12 (IO8), U5.27 (SDA), U6.27 (SDA), U7.24 (SDA)
INTER_UART_RX: U1.8 (IO15), U8.36 (RXD0)
INTER_UART_TX: U1.9 (IO16), U8.37 (TXD0)
LDO_IN: C_ISO1.1, C_ISO2.1, D_ISO1.2 (A), U4.3 (VI)
LED_STATUS: D_STAT1.1 (K), R_STAT1.1, U1.38 (IO2)
MPU_INT: U1.11 (IO18), U7.12 (INT)
unnamed: BZ1.1 (+), R_BZ1.2
unnamed: D_CATCH_L1.2 (A), L_SERVO_L1.1, U3_L1.3 (SW)
unnamed: D_CATCH_R1.2 (A), L_SERVO_R1.1, U3_R1.3 (SW)
unnamed: J2.A5 (CC1), R_CC3.1
unnamed: J2.B5 (CC2), R_CC4.1
unnamed: J3.A5 (CC1), R_VIS_CC1.1
unnamed: J3.B5 (CC2), R_VIS_CC2.1
unnamed: LED_3V3.2 (A), R_3V3_LED1.1
unnamed: LED_L1.2 (A), R_LED_L1.1
unnamed: LED_R1.2 (A), R_LED_R1.1
unnamed: LED_RGB_MAIN1.3 (DIN), R_NEO1.2
unnamed: Q_CAM_LED1.1 (G), R_CAM_LED1.2, R_PD_CAM_LED1.1
unnamed: R_NEO1.1, U1.25 (IO48)
unnamed: U3.13 (BAT), U3.14 (BAT)
unnamed: U3.15 (SNS), U3.16 (SNS)
unnamed: U3.17 (SW), U3.18 (SW)
unnamed: U3.19 (GND), U3.20 (GND), U3.25 (GND)
unnamed: U3.21 (PMID), U3.22 (PMID)
unnamed: R_FB1_L1.1, R_FB2_L1.1, U3_L1.2 (FB)
unnamed: R_FB1_R1.1, R_FB2_R1.1, U3_R1.2 (FB)
unnamed: C_MPU5.1, U7.20 (CPOUT)
unnamed: C_MPU2.1, U7.10 (REGOUT)
PWM_L_0: J_L4_C1.3, U6.6 (LED0)
PWM_L_1: J_L4_F1.3, U6.7 (LED1)
PWM_L_2: J_L4_T1.3, U6.8 (LED2)
PWM_L_3: J_L5_C1.3, U6.9 (LED3)
PWM_L_4: J_L5_F1.3, U6.10 (LED4)
PWM_L_5: J_L5_T1.3, U6.11 (LED5)
PWM_L_6: J_L6_C1.3, U6.12 (LED6)
PWM_L_7: J_L6_F1.3, U6.13 (LED7)
PWM_L_8: J_L6_T1.3, U6.15 (LED8)
PWM_L_9: J_AUX4.3, U6.16 (LED9)
PWM_L_10: J_AUX5.3, U6.17 (LED10)
PWM_L_11: J_AUX6.3, U6.18 (LED11)
PWM_R_0: J_L1_C1.3, U5.6 (LED0)
PWM_R_1: J_L1_F1.3, U5.7 (LED1)
PWM_R_2: J_L1_T1.3, U5.8 (LED2)
PWM_R_3: J_L2_C1.3, U5.9 (LED3)
PWM_R_4: J_L2_F1.3, U5.10 (LED4)
PWM_R_5: J_L2_T1.3, U5.11 (LED5)
PWM_R_6: J_L3_C1.3, U5.12 (LED6)
PWM_R_7: J_L3_F1.3, U5.13 (LED7)
PWM_R_8: J_L3_T1.3, U5.15 (LED8)
PWM_R_9: J_AUX1.3, U5.16 (LED9)
PWM_R_10: J_AUX2.3, U5.17 (LED10)
PWM_R_11: J_AUX3.3, U5.18 (LED11)
SERVO_OE: R_OE1.2, U1.18 (IO10), U5.23 (~OE), U6.23 (~OE)
TOF_RXD: J_TOF1.3, U8.39 (IO1)
TOF_TXD: J_TOF1.4, U8.38 (IO2)
UART_RX: J_UART1.4, U1.36 (RXD0)
UART_TX: J_UART1.3, U1.37 (TXD0)
USB_D+: J1.A6 (D+), J1.B6 (D+), J2.A6 (D+), J2.B6 (D+), U1.14 (USB_D+)
USB_D-: J1.A7 (D-), J1.B7 (D-), J2.A7 (D-), J2.B7 (D-), U1.13 (USB_D-)
VBAT: C_BAT1.1, C_BAT2.1, J_BAT1.1, J_SW_EXT1.1, SW_PWR1.1, U2.13 (BAT), U2.14 (BAT)
VBAT_SENSE: C_DIV1.1, R_DIV1.2, R_DIV2.1, U1.39 (IO1)
VBAT_SW: C_IN1_L1.1, C_IN1_R1.1, C_IN2_L1.1, C_IN2_R1.1, C_TOF_IN1.1, C_VIS_IN1.1, D_ISO1.1 (K), J_SW_EXT1.2, R_DIV1.1, SW_PWR1.2, SW_PWR1.3, U3_L1.5 (VIN), U3_R1.5 (VIN), U_LDO_VIS1.3 (VI), U_REG_5V_TOF1.3 (VI)
VBUS: C_VBUS1.1, C_VBUS2.1, J1.A4 (VBUS), J1.A9 (VBUS), J1.B4 (VBUS), J1.B9 (VBUS), LED_CHG1.1 (K), LED_FULL1.1 (K), L_CHG1.1, R_CHG1.1, R_FULL1.1, U2.21 (PMID), U2.22 (PMID), U2.23 (VBUS)
VBUS_MAIN: C_VBUS_MAIN1.2, J2.A4 (VBUS), J2.A9 (VBUS), J2.B4 (VBUS), J2.B9 (VBUS)
VBUS_VIS: C_VBUS_VIS1.2, J3.A4 (VBUS), J3.A9 (VBUS), J3.B4 (VBUS), J3.B9 (VBUS)
VISION_RESET: C_VIS_EN1.2, R_VIS_EN1.2, SW_VIS_RST1.2, U1.22 (IO14), U8.3 (EN)
VISION_SYNC: U1.4 (IO4), U8.23 (IO21)
VIS_USB_D+: J3.A6 (D+), J3.B6 (D+), U8.14 (USB_D+)
VIS_USB_D-: J3.A7 (D-), J3.B7 (D-), U8.13 (USB_D-)
V_SERVO_L: C_OUT1_L1.1, C_OUT2_L1.1, C_OUT3_L1.1, J_AUX4.2, J_AUX5.2, J_AUX6.2, J_L4_C1.2, J_L4_F1.2, J_L4_T1.2, J_L5_C1.2, J_L5_F1.2, J_L5_T1.2, J_L6_C1.2, J_L6_F1.2, J_L6_T1.2, LED_L1.1 (K), L_SERVO_L1.2, R_FB1_L1.2
V_SERVO_R: C_OUT1_R1.1, C_OUT2_R1.1, C_OUT3_R1.1, J_AUX1.2, J_AUX2.2, J_AUX3.2, J_L1_C1.2, J_L1_F1.2, J_L1_T1.2, J_L2_C1.2, J_L2_F1.2, J_L2_T1.2, J_L3_C1.2, J_L3_F1.2, J_L3_T1.2, LED_R1.1 (K), L_SERVO_R1.2, R_FB1_R1.2

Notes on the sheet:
SECTION 8: MPU-6050 6-DOF IMU
Dual XL4015 Converters: V_SERVO_R (Right Servos) & V_SERVO_L (Left Servos)
SECTION 9: ESP32-S3 VISION COPROCESSOR & TRIPLE USB-C INTERFACE
SECTION 4: 3.3V SYSTEM LOGIC LDO
TP5100 / BQ25886 8.4V/1.5A Switching Fast Charger with CC Detection
Dual PCA9685PW 12-Bit PWM Drivers (0x40 & 0x41)
SECTION 7: 18-DOF SERVO HEADERS & AUX PWM
Dual AMS1117 LDOs, OV3660 DVP Camera, MaixSense ToF Sensor, LED Spotlight Driver, Dual Type-C Ports
SECTION 1: USB TYPE-C & 2S LIPO CHARGER
SECTION 3A: RIGHT SERVO BUCK (5V/5A, V_SERVO_R)
SECTION 2: BATTERY & TELEMETRY
3-Pin Headers (GND, 5V, PWM): Legs 1-6 (Coxa, Femur, Tibia) + 6 AUX PWM
SECTION 5: ESP32-S3-WROOM-1 MCU
SECTION 6: DUAL 16-CH PWM CONTROLLERS
SECTION 3B: LEFT SERVO BUCK (5V/5A, V_SERVO_L)
AMS1117-3.3 Low-Noise Supply for ESP32-S3 and PCA9685 Logic
Dual-core 240MHz XTensa, Auto-Reset, Boot, UART & I2C Expansion
XT30 2S LiPo Input, Power Switch, Diode & 1% ADC Telemetry Divider
SECTION 3: DUAL 5V/5A SERVO BUCK REGULATORS (10A TOTAL)

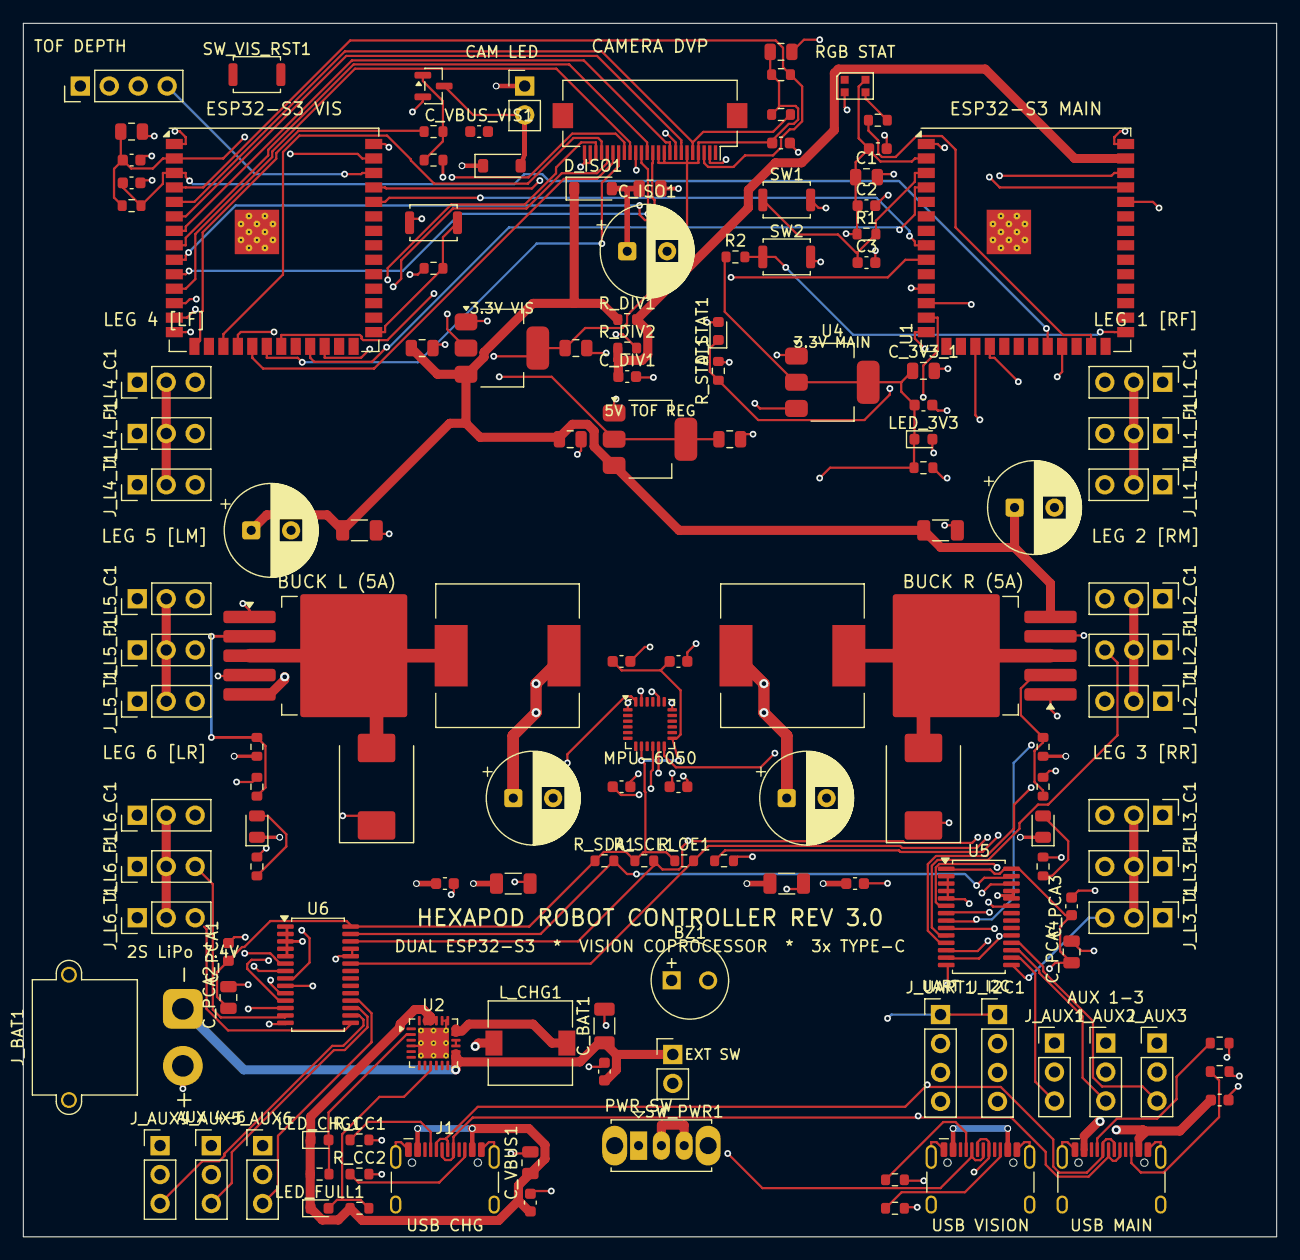
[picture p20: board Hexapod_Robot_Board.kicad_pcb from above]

Board: 4 copper layers, 110.0 x 106.5 mm, 139 parts (0 on the bottom side), 97 nets.

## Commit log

2026-09-28 Initial commit: 18-DOF Hexapod Robot Controller PCB (4-Layer, 0-DRC, ESP32-S3, Dual PCA9685, TP5100 2S Charger, MP1584 Buck, Full Fabrication Package)
    [Hexapod_Robot_Board-B_Courtyard.gbr, Hexapod_Robot_Board-B_Cu.gbl, Hexapod_Robot_Board-B_Fab.gbr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]
2026-09-28 Enhance schematic design: 7 clean functional blocks, physical wire traces, and 0-ERC validation
    [Hexapod_Robot_Board.kicad_sch]
2026-09-29 fix: invert USB-C orientation, clear ESP32 antenna keepout, achieve 0 DRC/ERC violations, and update 3D/fab outputs
    [AMASS_XT30PW-M_1x02_P2.50mm_Horizontal.step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]
2026-10-01 feat(pcb): complete Rev 2.0 4-layer routing, achieve 0 DRC / 0 ERC, and export fabrication package
    [Hexapod_Robot_Board-B_Courtyard.gbr, Hexapod_Robot_Board-B_Cu.gbl, Hexapod_Robot_Board-B_Fab.gbr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]
2026-10-01 chore: structure project repository, remove redundant files, and add export_fabrication pipeline
    [Hexapod_Robot_Board-B_Cu.gbl, Hexapod_Robot_Board-B_Mask.gbs, Hexapod_Robot_Board-B_Paste.gbp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]
2026-10-01 feat(3d): integrate official 3D models for ESP32-S3-WROOM-1U and MPU-6050
    - Add ESP32-S3-WROOM-1U.step (8.3MB official Espressif SolidWorks AP214 model)
    - Add InvenSense_QFN-24_4x4mm_P0.5mm.step for MPU-6050 U7 footprint
    - Migrate all local model paths from hardcoded absolute to ${KIPRJMOD}/3dmodels/
    (AMASS XT30, L_7.3x7.3, USB-C, ESP32-S3, MPU-6050) for portable cross-machine builds
    - Regenerate complete fabrication package: STEP (9.5MB), Gerbers, CPL, BOM, renders
    - Regenerate 2400x1800 high-resolution raytraced renders (3D, Top, Bottom)
    - kicad-cli pcb export step: 0 missing model warnings
    Fixes: missing 3D models reported for U1 and U7 in board review
    [ESP32-S3-WROOM-1U.step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]
2026-10-01 fix(3d): correct ESP32-S3-WROOM-1U 3D model alignment offset
    The official Espressif SolidWorks STEP file uses a non-centered origin:
    - STEP X=0 is at the left body edge (not module center)
    - STEP Y=0 is at the antenna tip of the full 25.5mm module (not footprint center)
    Applied offsets to align with KiCad footprint coordinate system:
    X = -9.0mm (centers 18mm body: STEP body 0..18 -> KiCad -9..+9)
    Y = -9.6mm (aligns full module: STEP Y=19.2 -> KiCad Y=+9.6 bottom of footprint)
    Z = 0.0mm (no height correction needed)
    Module now correctly sits on board with 6.3mm antenna section
    protruding beyond top board edge (as designed for WROOM-1U)
    [Hexapod_Robot_Board.kicad_pcb]
2026-10-04 feat(rev3): Rev 3.0 — Dual ESP32-S3, Vision Coprocessor, BQ25886 charger, triple USB-C, ToF + Camera subsystem
    Major architectural upgrade from Rev 2.0:
    - Add Vision Coprocessor (ESP32-S3-WROOM-1U-N8R8, U8) — Zephyr esp32s3_eye compatible
    - Replace TP5100 with BQ25886 2S LiPo fast charger (PowerPath, USB BC1.2, I2C status)
    - Triple South-edge USB-C: J_CHG (dedicated charger), J2 (Main MCU JTAG), J3 (Vision JTAG/video)
    - Add 24-pin DVP FPC camera interface (OV3660/OV2640, J_CAM) at top-centre
    - Add MaixSense A010 3D ToF (J_TOF) on isolated +5V_TOF linear rail (AMS1117-5.0)
    - Add dedicated Vision 3.3V LDO (U_LDO_VIS, AMS1117-3.3) for +3V3_VIS rail
    - Add 1-3W camera LED driver (AO3400A Q_CA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
    [Hexapod_Robot_Board.kicad_pcb, Hexapod_Robot_Board.kicad_sch, Hirose_FH12-24S-0.5SH_1x24-1MP_P0.50mm_Horizontal.step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]
2026-10-07 servo pwm alignments. repo & schematic cleanup
    [Hexapod_Robot_Board-B_Cu.gbl, Hexapod_Robot_Board-B_Mask.gbs, Hexapod_Robot_Board-B_Paste.gbp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]

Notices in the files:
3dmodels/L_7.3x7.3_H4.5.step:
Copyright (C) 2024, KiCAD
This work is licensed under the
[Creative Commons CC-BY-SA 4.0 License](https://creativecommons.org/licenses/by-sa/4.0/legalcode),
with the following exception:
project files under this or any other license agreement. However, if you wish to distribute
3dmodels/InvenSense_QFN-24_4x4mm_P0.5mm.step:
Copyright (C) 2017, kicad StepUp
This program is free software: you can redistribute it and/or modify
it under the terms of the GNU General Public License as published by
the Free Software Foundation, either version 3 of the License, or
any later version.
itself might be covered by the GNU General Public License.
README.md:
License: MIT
